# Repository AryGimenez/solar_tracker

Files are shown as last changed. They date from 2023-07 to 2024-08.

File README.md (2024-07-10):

# Solar Tracker

Este es el código y documentación para el proyecto Solar Tracker, que es un dispositivo que se encarga de seguir automáticamente el movimiento del sol para mantener un panel solar siempre orientado hacia él y maximizar la eficiencia de la celda fotovoltaica.

**Descripción del Proyecto**  
El Solar Tracker utiliza un **Arduino** como su controlador principal. Cuenta con dos servomotores **Hitec HS-422**: uno para el movimiento vertical y otro para el movimiento horizontal del panel solar. Además, tiene cuatro fotorresistencias (**LDR 5538**) colocadas estratégicamente para detectar la posición del sol.

El proyecto tiene tres modos de funcionamiento, que se pueden seleccionar mediante botones y se indican mediante LEDs:

- **Modo Manual**: En este modo, los servos están controlados por un módulo Arduino Joystick **(Modelo KY 023)**, permitiendo al usuario realizar el seguimiento del sol de forma manual.

- **Modo Solo Motor Horizontal**: En este modo, el servomotor vertical se detiene, y el servomotor horizontal sigue automáticamente las órdenes proporcionadas por las fotorresistencias para mantener el panel solar orientado horizontalmente hacia el sol.

- **Modo Automático**: En este modo, ambos servomotores siguen automáticamente el movimiento del sol, ajustándose tanto en el eje vertical como en el horizontal para mantener el panel solar siempre en dirección al sol.

El Solar Tracker también incluye un módulo de reloj **Tiny RTC** para mantener la fecha y hora actualizada. Además, cuenta con un sensor de corriente **ACS712** para medir el voltaje, amperaje y potencia del panel solar.

Los datos medidos se guardan en una tarjeta microSD en formato JSON, junto con el lugar físico donde se encuentra el Solar Tracker. La tarjeta microSD también almacena la variable **mIntervaloSensado**, que define el intervalo en minutos en el que se deben guardar los datos.

El dispositivo está equipado con un display **OLED SSD1306** de 0.96" para mostrar información relevante, como el lugar físico, fecha y hora actual, voltaje, amperaje, potencia y nivel de batería. Además, si hay algún problema con la tarjeta SD, se mostrará un mensaje de error en el display.

**Estructura del Proyecto**  
- **Codigo**: Todo el código del Solar Tracker.
- **Diagrama_Electrico**: Esquemas en Fritzing e imágenes de los diagramas esquemáticos y el PCB.
- **Diseño 3D**: Diseños para imprimir la estructura en impresora 3D.
- **Proyecto-Ejemplo**: Código de un proyecto similar que sirve como base, pero con algunas funcionalidades adicionales en este proyecto.
- **SolarTraker-Ejemplo**: Código del proyecto de referencia.

**Instalación y Configuración**  
Para utilizar el Solar Tracker, sigue estos pasos:

1. Conecta los componentes según se indica en el código y asegúrate de tener las bibliotecas adecuadas instaladas en tu entorno de desarrollo.
2. Carga el código del Solar Tracker en tu Arduino Mega 2560 utilizando PlatformIO Labs.
3. Conecta el Arduino a una fuente de alimentación y asegúrate de que todos los componentes estén correctamente conectados.
4. Utiliza los botones para seleccionar el modo de funcionamiento deseado y observa cómo el panel solar sigue automáticamente la posición del sol.
5. El display OLED mostrará información actualizada, incluyendo el lugar físico, fecha y hora actual, voltaje, amperaje, potencia y nivel de batería.
6. Para cambiar la configuración del Solar Tracker, como el intervalo de sensado o la fecha del reloj Tiny RTC, utiliza la APK desarrollada en Python para comunicarte con el dispositivo a través del módulo Bluetooth HM-05.

**APK (Aplicación Python)**  cambiar por el id que va 
La comunicación con el Solar Tracker se realiza mediante una APK desarrollada en Python. La APK puede enviar comandos para cambiar el intervalo de sensado, la fecha del reloj Tiny RTC y el lugar físico del Solar Tracker. Además, puede recibir datos del Solar Tracker en formato JSON, incluyendo la hora y fecha actual, voltaje, amperaje, potencia y los datos almacenados en la tarjeta microSD.

Para desarrollar la APK, se puede utilizar la biblioteca **PySerial** para la comunicación por puerto serie y la biblioteca **Requests** para enviar y recibir datos JSON.

**Notas Finales**  
El proyecto del Solar Tracker es una solución eficiente para maximizar la eficiencia de un panel solar al seguir automáticamente el movimiento del sol a lo largo del día. Con la posibilidad de controlar el dispositivo mediante la APK, se pueden realizar ajustes y recibir información actualizada de manera remota.

Esperamos que este proyecto te sea útil y te inspire en futuros desarrollos. Si tienes alguna pregunta o necesitas ayuda adicional, no dudes en consultar la documentación o preguntar en la comunidad.

¡Disfruta de tu Solar Tracker y el aprovechamiento de la energía solar!

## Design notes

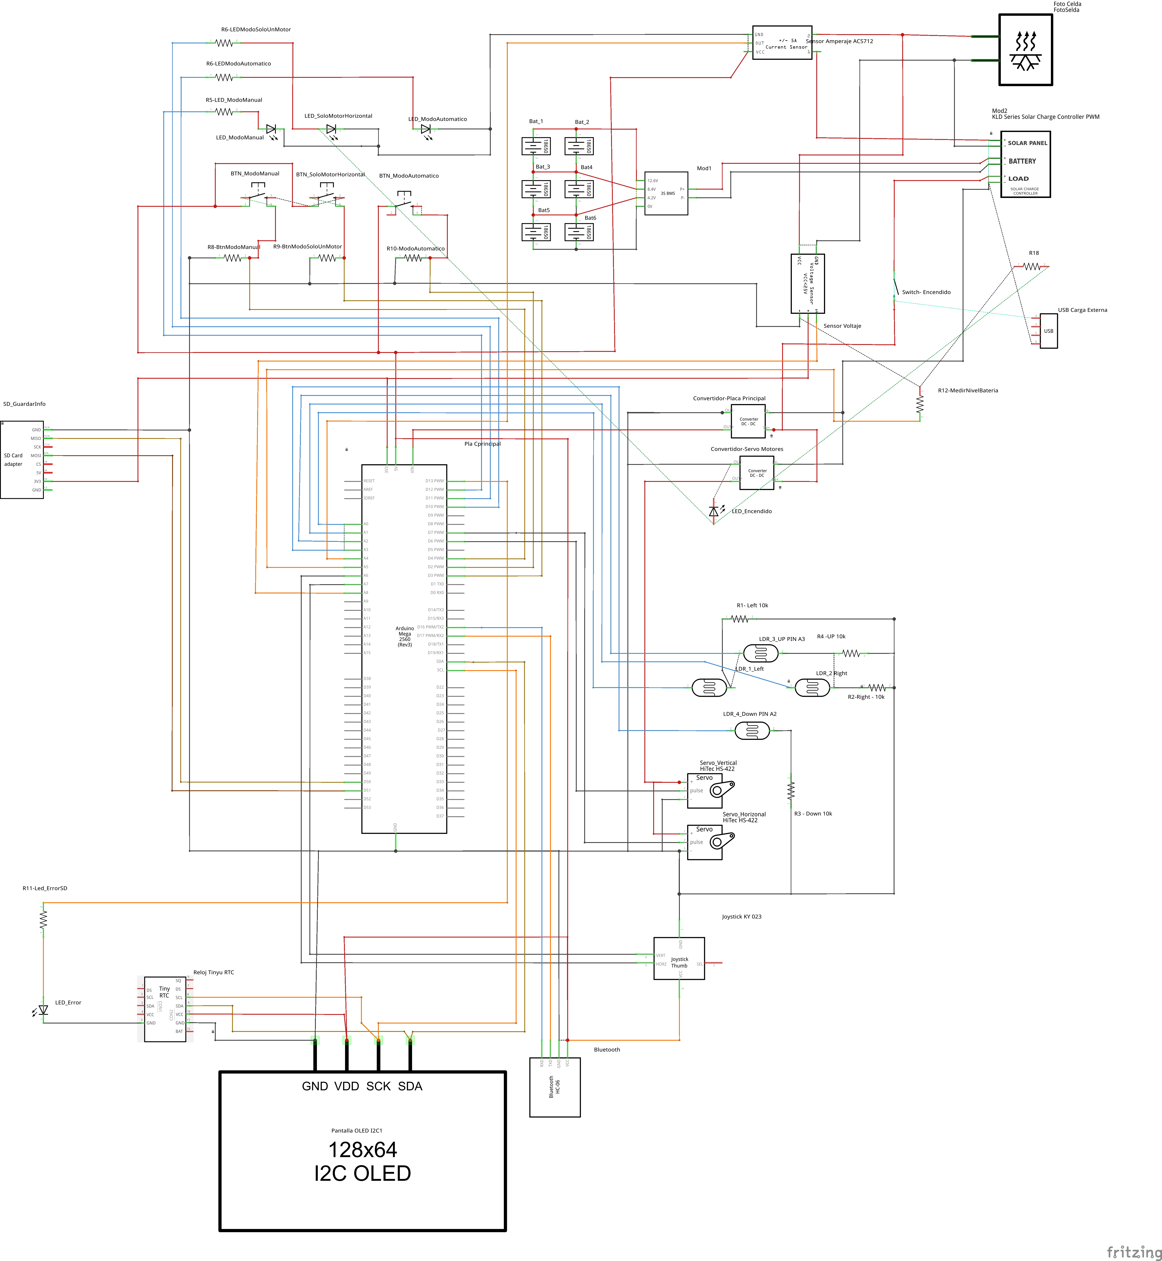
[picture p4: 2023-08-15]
Diagrama_Electrico/Diagrama Solar Tracker - Arduino Mega_Esquemático.jpg

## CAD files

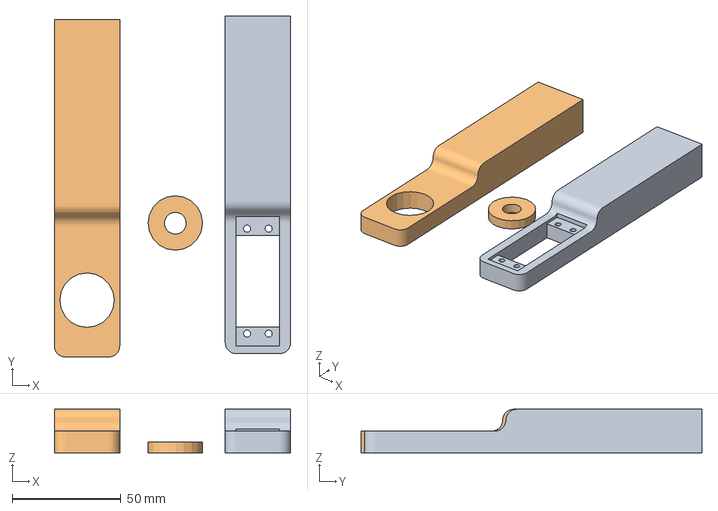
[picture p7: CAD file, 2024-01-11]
Diseño 3d/Para Imprimir/Pilar pantalla eje y motor 155 mm.3mf
108.4 x 156.5 x 20.0 mm
Pilar motor 155mm.stl
Pilar eje 155 mm.stl

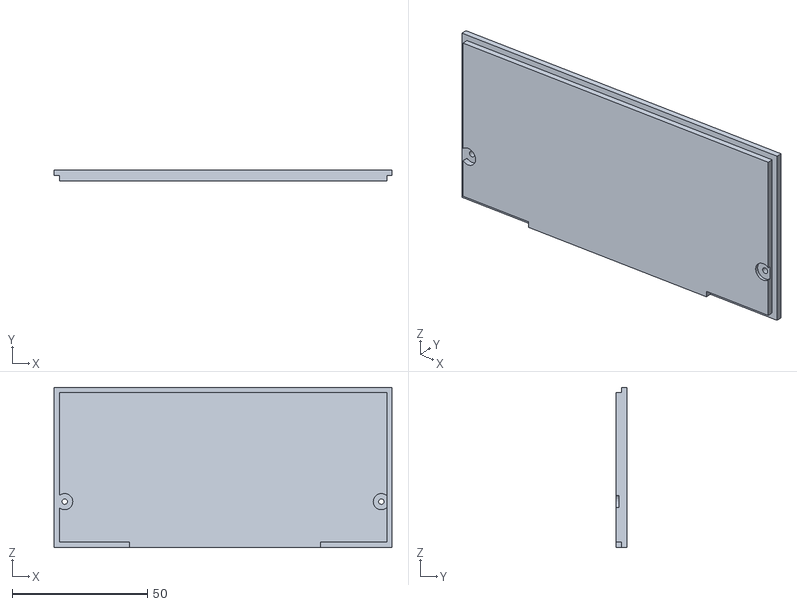
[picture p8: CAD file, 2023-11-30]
Diseño 3d/STL - Diseño 3d/Visor (Tapa).stl
124.9 x 4.00 x 59.2

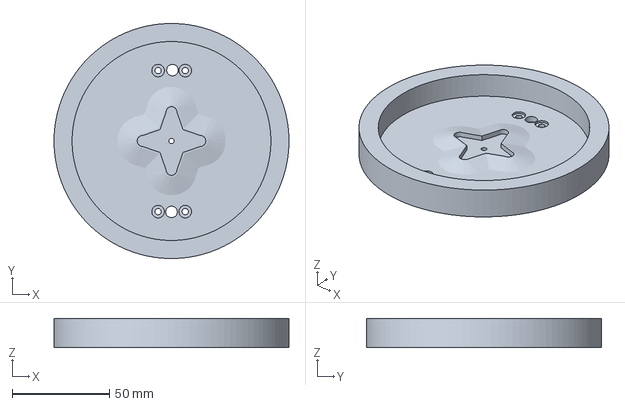
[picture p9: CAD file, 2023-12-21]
Diseño 3d/Para Imprimir/Base Giratoria.3mf
121.0 x 121.0 x 15.0 mm

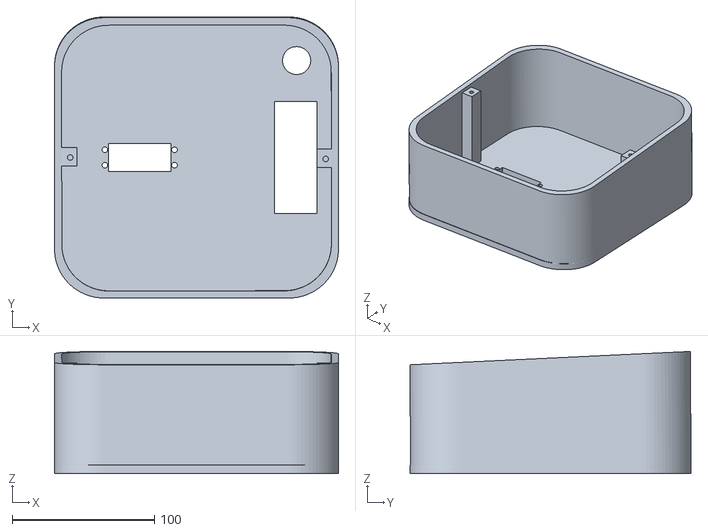
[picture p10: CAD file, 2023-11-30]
Diseño 3d/STL - Diseño 3d/Base Sokar Tracker (8cm pilares sujecion).stl
200.0 x 198.0 x 86.0

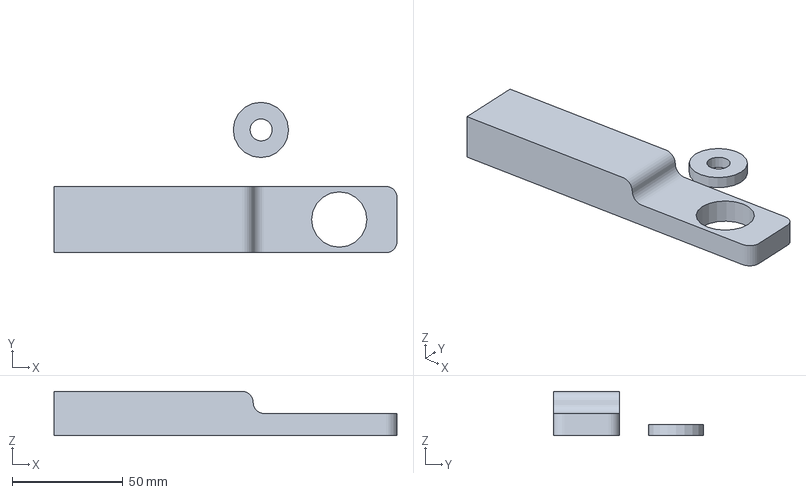
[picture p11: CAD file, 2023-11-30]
Diseño 3d/Para Imprimir/Pilar eje 155 mm.3mf
155.0 x 68.0 x 20.0 mm

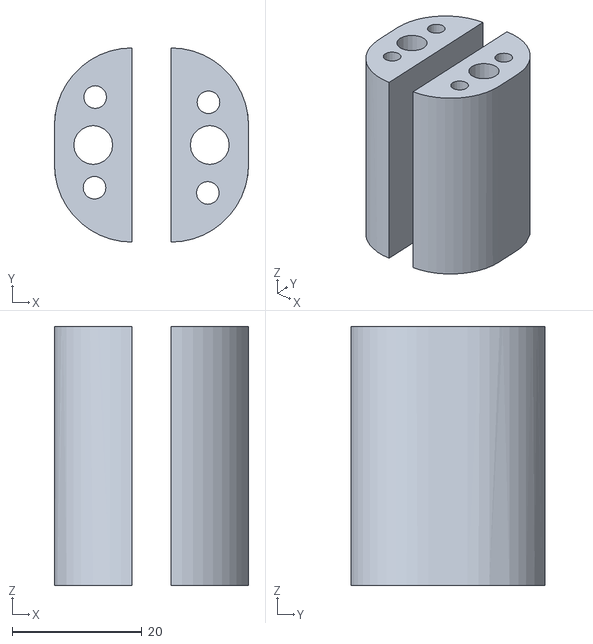
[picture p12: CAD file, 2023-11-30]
Diseño 3d/STL - Diseño 3d/Pilares coneccion Giratorio (40mm).stl
30.0 x 30.0 x 40.0

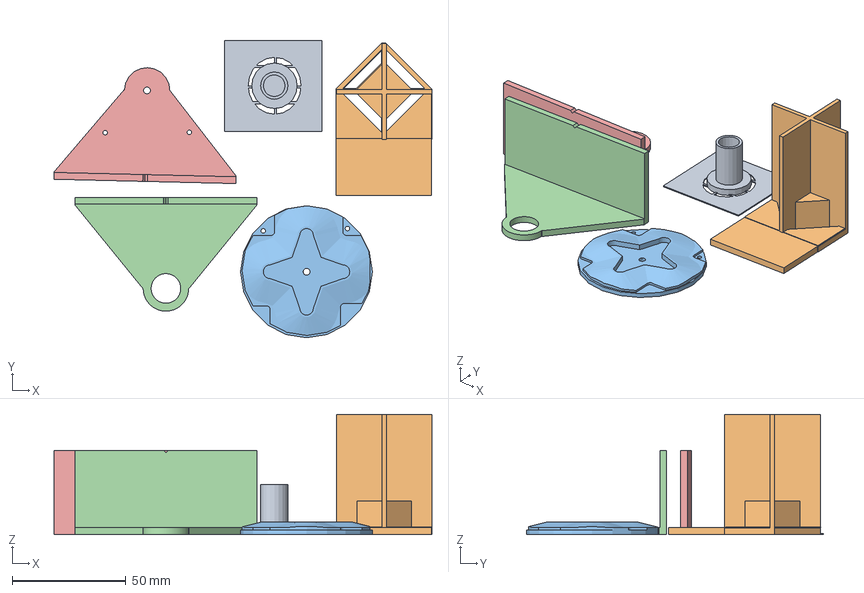
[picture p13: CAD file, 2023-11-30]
Diseño 3d/Para Imprimir/Piesas Chicas (Piesas Sujecion a celda Fotovoltacia - Sensor RGB).3mf
166.1 x 130.7 x 52.8 mm
Soporte Celda Fotovoltaica (Soporte para Eje 2).stl
Sensor RGH luz.stl
Soporte Sujecion motor 2.stl
Soporte Sujecion Eje.stl
Soporte Sujecion motor 1.stl

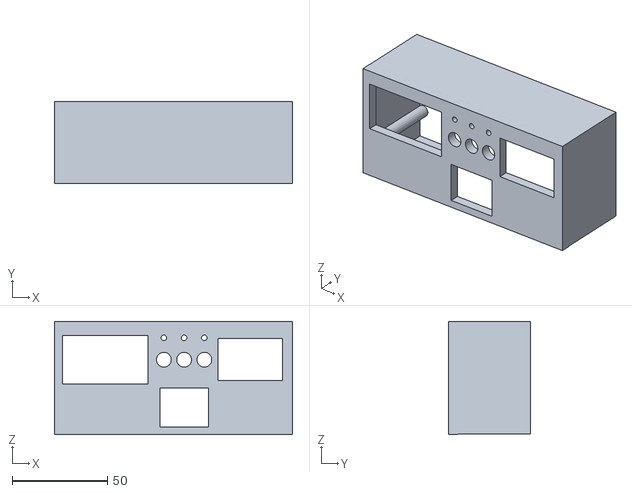
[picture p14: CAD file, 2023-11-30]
Diseño 3d/STL - Diseño 3d/Visor.stl
125.1 x 43.0 x 59.5

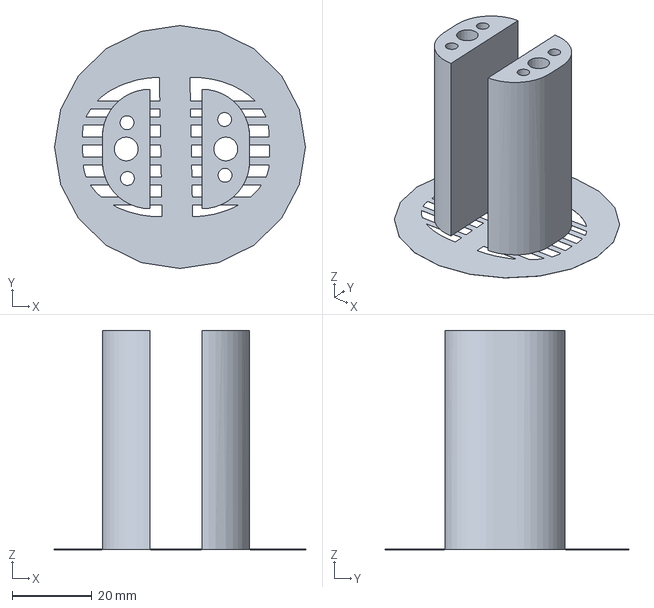
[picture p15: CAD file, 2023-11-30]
Diseño 3d/Para Imprimir/Pilares coneccion Giratorio (55mm) Con Base Imprecion.3mf
63.0 x 61.0 x 55.0 mm

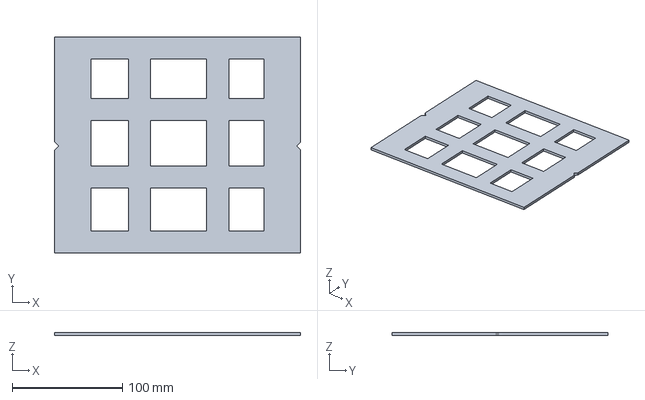
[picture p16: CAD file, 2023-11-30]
Diseño 3d/Para Imprimir/Soporte Celda Fotovoltaica.3mf
223.0 x 196.0 x 3.00 mm

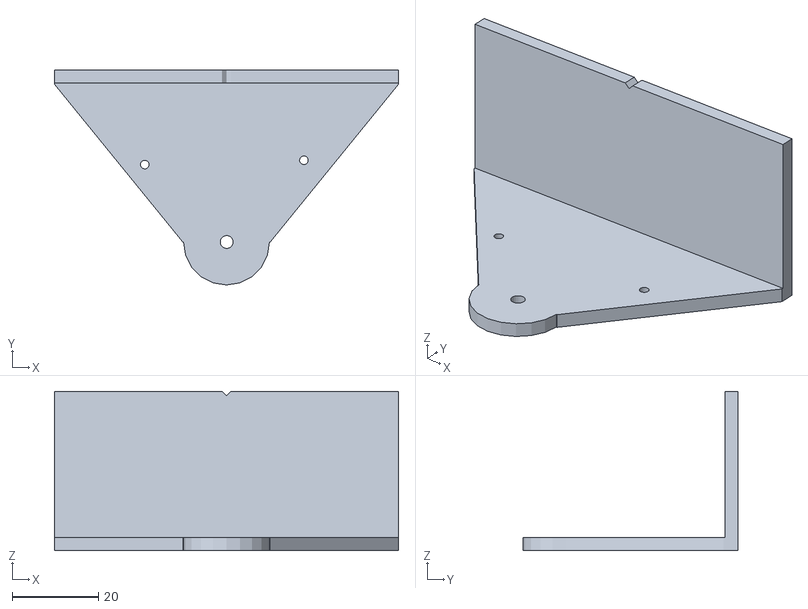
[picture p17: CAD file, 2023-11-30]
Diseño 3d/STL - Diseño 3d/Soporte Sujecion motor 1.stl
80.0 x 50.0 x 37.0

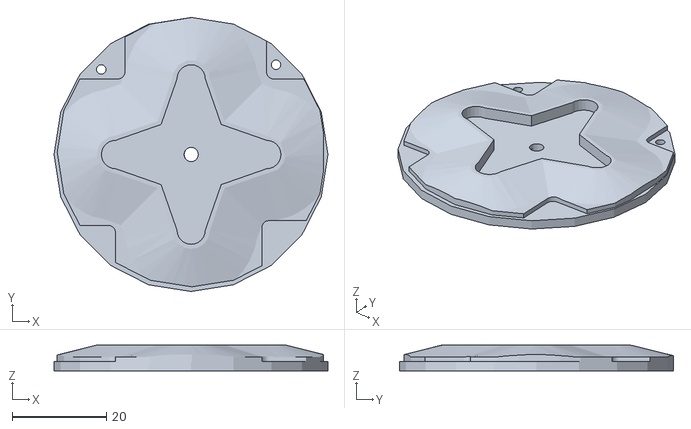
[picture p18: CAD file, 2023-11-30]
Diseño 3d/STL - Diseño 3d/Soporte Sujecion motor 2.stl
58.0 x 58.0 x 5.50

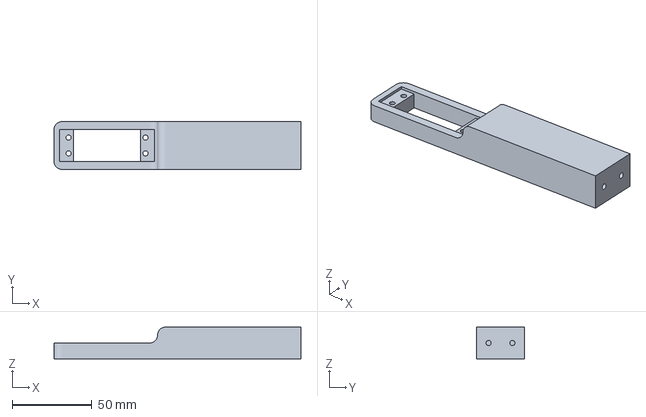
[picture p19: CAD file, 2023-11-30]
Diseño 3d/Para Imprimir/CE3E3V2_Pilar motor 155mm.3mf
155.0 x 30.0 x 20.0 mm

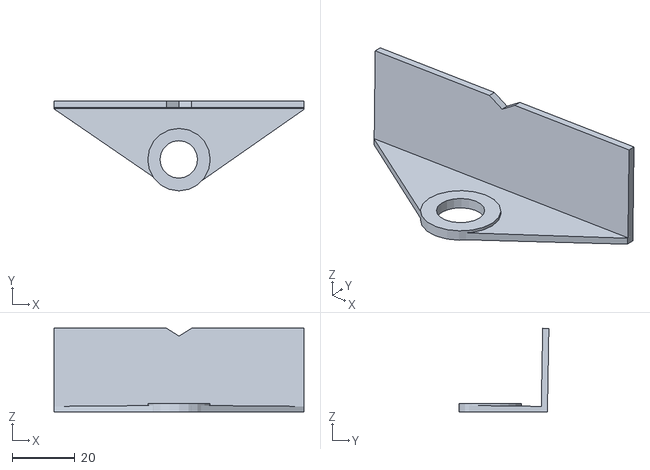
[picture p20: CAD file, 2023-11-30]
Diseño 3d/STL - Diseño 3d/Soporte Celda Fotovoltaica (Soporte para Eje 1).stl
80.0 x 28.7 x 26.7

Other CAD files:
Diseño 3d/STL - Diseño 3d/Pilar eje 155 mm.stl
Diseño 3d/Para Imprimir/Pilar Coneccion Giratorio (40mm).3mf
Diseño 3d/STL - Diseño 3d/Soporte Sujecion Eje.stl
Diseño 3d/Para Imprimir/Base Sokar Tracker (80 cm).3mf
Diseño 3d/Para Imprimir/Base Sokar Tracker.3mf
Diseño 3d/Para Imprimir/Sensor RGH luz.3mf
Diseño 3d/Para Imprimir/Tapa con patitas Base Solar Traker.3mf
Diseño 3d/STL - Diseño 3d/Base Giratoria.stl
Diseño 3d/STL - Diseño 3d/Base Sokar Tracker (Borde 5 mm).stl.stl
Diseño 3d/STL - Diseño 3d/Base Sokar Tracker (Solo - Borde 10 mm).stl
Diseño 3d/STL - Diseño 3d/Base Sokar Tracker (Solo - Borde 5 mm).stl
Diseño 3d/STL - Diseño 3d/Base Solar Tracker (Parte Superior).stl
Diseño 3d/STL - Diseño 3d/Conector para eje metal.stl
Diseño 3d/STL - Diseño 3d/Pilar motor 155mm.stl
Diseño 3d/STL - Diseño 3d/Pilares coneccion Giratorio (40mm) Con Base Imprecion.stl
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

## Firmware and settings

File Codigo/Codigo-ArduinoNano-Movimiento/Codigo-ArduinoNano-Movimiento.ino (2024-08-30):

#include <Servo.h>





// VARIABLES -------------------------------------------------------------------

// ---- Declaraciones de constantes para los pines ----


const int PIN_BTNModoManual = 2;          // Botón para el modo manual
const int PIN_LEDModoManual = 7;          // LED para el modo manual
const int PIN_BTNModoAutomatico = 4;      // Botón para el modo automático
const int PIN_LEDModoAutomatico = 8;      // LED para el modo automático

// Variable para guardar el modo de usos seleccionado
bool modoManualActivo = false;  // MOdo de uso LDR activado por defect\



// ⚡  Sensor voltaje Amperaje ------------------------------

  // Pines para los sensores de amperaje y voltaje
  const int PIN_SensorAmperaje = A6;        // Pin para el sensor de amperaje
  const int PIN_SensorVoltaje = A7;         // Pin para el sensor de voltaje

  // Variables para guardar mediciones de amperaje y voltaje
  float currentAmperage = 0.0;
  float currentVoltage = 0.0;


// ⚡  FIN Sensor voltaje Amperaje ------------------------------


// Pines del joystick KY 023 🕹️ ------------------------------


  const int PIN_JoystickX = A4;             // Pin para el eje X del joystick
  const int PIN_JoystickY = A5;             // Pin para el eje Y del joystick// Pines para los sensores LDR


// 🕹️ FIN ------------------------------


// 📡 Sensor LDR ------------------------------

    // Definición de los pines de las fotorresistencias 🌞
    const int PIN_LDR_Arriba = A0;            // ⬆️ - Pin para el LDR de "Arriba"
    const int PIN_LDR_Izquierda = A3;         // ➡️ - Pin para el LDR de "Izquierda" 
    const int PIN_LDR_Abajo = A2;             // ⬇️ - Pin para el LDR de "Abajo"
    const int PIN_LDR_Derecha = A1;           // ⬅️ - Pin para el LDR de "Derecha"

// 📡 FIN Sensor LDR -----------------------------


// ⚙️ Atributos Servos ------------------------------
  // ⬆️⬇️ 10 Pin Vertical - Ubicado en la pantalla solar
  // ⬅️➡️ 11 Pin Hotizontal - Ubicado En el eje del soporto 

  // Declaraciones para los servos
  const int PIN_ServoHorizontal = 11;       // Pin para el servo horizontal
  const int PIN_ServoVertical = 10;         // Pin para el servo vertical

  // Objetos para controlar los servos
  Servo m_servoHorizontal;
  Servo m_servoVertical;

  // variables para guardar la ultima posicion de los servos
  int m_ServoHorizontalPosicion = 0;
  int m_ServoVerticalPosicion = 0;

  // Definición de constantes para la calibración y los límites de movimiento del servo
  const int MIN_ANGLE = 0;    // Ángulo mínimo del servomotor
  const int MAX_ANGLE = 180;  // Ángulo máximo del servomotor

  // Ajustar estos valores basados en las pruebas con el servo
  int pwmMin = 300;  // Valor PWM mínimo (ajustar según el servo) Defecto 600 
  int pwmMax = 2400; // Valor PWM máximo (ajustar según el servo)


  const int m_umbralSensibilidad = 5;   // Incremento en grados para cada ajuste del servo, utilizado para 
                              // calibrar la sensibilidad del sensor LDR y evitar respuestas 
                              // a pequeñas variaciones

// ⚙️ Fin atributos Servos ------------------------------



//METODOS -------------------------------------------------------------------


// ⚙️ Metodos Servos ------------------------------


  /**
   * @brief moveVertical
   * Funcion para mover el servomotor verticalmente
   * Si 'direction' es positivo (>0), mueve el servo hacia la arriba
   */
  void moveVertical(int direction) {
   
    // Calcula la nueva posición vertical del servomotor,
    // asegurándose de que esté dentro de los límites permitidos.
    // 'm_ServoVerticalPosicion' es la posición actual del servomotor.
    // 'direction' indica la dirección y magnitud del cambio de posición.
    // 'ANGLE_STEP' es la cantidad de grados que el servo debe moverse por cada unidad de 'direction'.
    // 'MIN_ANGLE' y 'MAX_ANGLE' son los límites mínimos y máximos, respectivamente, dentro de los cuales el servomotor puede moverse.
    

    // Guarda la nueva pocicione en sumandole la nueva funcion del angulo 
    int x_NuevaPocicionVertical = direction + m_ServoVerticalPosicion;


    // Verifica que la nueva posición esté en el rango apropiado.
    if (x_NuevaPocicionVertical < MIN_ANGLE || x_NuevaPocicionVertical > MAX_ANGLE)
      return;
      
    // Actualiza la posición del servomotor.
    m_ServoVerticalPosicion = x_NuevaPocicionVertical;

    moverServo(m_ServoVerticalPosicion,)

    // Imprime la nueva posición del servomotor vertical en el monitor serial para depuración y monitoreo.
    Serial.print("Servo Vertical: ");
    Serial.println(m_ServoVerticalPosicion);
  } // Fin de la función 'moveVertical'

  /**
   * @brief moveHorcizontal
   * Funcion para mover el servomotor horizontalmente
   * Si 'direction' es positivo (>0), mueve el servo hacia la derecha
   */
  void moveHorcizontal(int direction) {
    
    // Calcula la nueva posición horizontal del servomotor,
    // asegurándose de que esté dentro de los límites permitidos.
    // 'm_ServoHorizontalPosicion' es la posición actual del servomotor.
    // 'direction' indica la dirección y magnitud del cambio de posición.
    // 'ANGLE_STEP' es la cantidad de grados que el servo debe moverse por cada unidad de 'direction'.
    // 'MIN_ANGLE' y 'MAX_ANGLE' son los límites mínimos y máximos, respectivamente, dentro de los cuales el servomotor puede moverse.


    // Guarda la nueva pocicione en sumandole la nueva funcion del angulo 
    int x_NuevaPocicionHorizontal = direction + m_ServoHorizontalPosicion;


    // Verifica que la nueva posición esté en el rango apropiado.
    if (x_NuevaPocicionHorizontal < MIN_ANGLE || x_NuevaPocicionHorizontal > MAX_ANGLE)
      return;
      
    // Actualiza la posición del servomotor.
    m_ServoHorizontalPosicion = x_NuevaPocicionHorizontal;
   

    moverServo(m_ServoHorizontalPosicion, m_servoHorizontal)
 
    // Imprime la nueva posición del servomotor horizontal en el monitor serial para depuración y monitoreo.
    Serial.print("Servo Horizontal: ");
    Serial.println(m_ServoHorizontalPosicion);
  } // Fin de la función 'moveHorizontal'

  /**
  * 
  **/
  void moverServo(int p_Grados, Servo p_ServoAMover){
    int xPWM_Temp = map(p_Grados, 
      MIN_ANGLE, // Valor mínimo de la posición del servomotor
      MAX_ANGLE, // Valor máximo de la posición del servomotor
      pwmMin, // Valor minimo del PWM
      pwmMax); // Valor maximo del PWM

    // Mueve Servo
    p_ServoAMover.write(xPWM_Temp);

  }

 /**
  * @def controlarSerfosConLDR
  * para controlar servos con el sensor LDR
  **/
    void controlarServosConLDR() {
      // Aquí el código para mover los servos con los sensores LDR
      int valorLDRArriba = analogRead(PIN_LDR_Arriba);
      int valorLDRDerecha = analogRead(PIN_LDR_Derecha);
      int valorLDRAbajo = analogRead(PIN_LDR_Abajo);
      int valorLDRIzquierda = analogRead(PIN_LDR_Izquierda);


      Serial.print("Arriba: ");
      Serial.print(valorLDRArriba);
      Serial.print(" | Derecha: ");
      Serial.print(valorLDRDerecha);
      Serial.print(" | Abajo: ");
      Serial.print(valorLDRAbajo);
      Serial.print(" | Izquierda: ");
      Serial.println(valorLDRIzquierda);
      
      // Determinar la dirección de la luz más intensa de lado vertical
      if (abs(valorLDRArriba - valorLDRAbajo) > m_umbralSensibilidad ) {
        if (valorLDRArriba > valorLDRAbajo) {
          moveVertical(1); // Mover hacia arriba
        } else {
          moveVertical(-1); // Mover hacia abajo
        }
      }

      // Determinar la dirección de la luz más intensa de lado horizontal
      if (abs(valorLDRDerecha - valorLDRIzquierda) > m_umbralSensibilidad) {
        if (valorLDRDerecha > valorLDRIzquierda) {
          moveHorcizontal(1); // Mover hacia la derecha
        } else {
          moveHorcizontal(-1); // Mover hacia la izquierda
        }
      }

    }




    /**
     * @def VerifiarEsadoSero
     * 
     */
    void VerifiarEsadoSero (boolean pVertica){
      
      if (pVertica){
        m_ServoVerticalPosicion = 0;
        moveVertical(0);
        
        for (int i = 0; i < 180; i++)
        {
          delay(1000);
          moveVertical(1);
        }

      }else{
        m_ServoHorizontalPosicion = 0;
        moveHorcizontal(0);
        
        for (int i = 0; i < 180; i++)
        {
          delay(1000);
          moveHorcizontal(1);
        }        
      }
  

      
    }

/**
 * @brief inicializarServos
 * Inicializa los servos y los mueve a la posición inicial.
 */

void inicializarServos() {

   m_servoHorizontal.attach(PIN_ServoHorizontal);             // Adjunta el servo horizInicializa ontal al pin 11
   m_servoVertical.attach(PIN_ServoVertical);               // Adjunta el servo vertical al pin 10
 
  moveHorcizontal(0);

  // Estableser Posición inicial de los servos
   m_servoHorizontal.write(180);             // Posición inicial del servo horizontal
   m_servoVertical.write(180);               // Posición inicial del servo vertical
}

// ⚙️ Fin Servos ------------------------------


// 📡 Sensor LDR ------------------------------

  /**
   * @def verificarSensoresLDR
   * Metodo utilizado para verificar los sentidos Del Sensor LDR  
   */ 
    void verificarSensoresLDR() {
    // Leer los valores analógicos de los sensores LDR
    int valorLDRArriba = analogRead(PIN_LDR_Arriba);
    int valorLDRDerecha = analogRead(PIN_LDR_Derecha);
    int valorLDRAbajo = analogRead(PIN_LDR_Abajo);
    int valorLDRIzquierda = analogRead(PIN_LDR_Izquierda);
    
    // Imprimir los valores leídos - Imprime: "LDR Up: valor, Right: valor, Down: valor, Left: valor"
    Serial.print("LDR Up: " + String(valorLDRArriba) + ", ");
    Serial.print("Right: " + String(valorLDRDerecha) + ", ");
    Serial.print("Down: " + String(valorLDRAbajo) + ", ");
    Serial.println("Left: " + String(valorLDRIzquierda));


    //Esperar 3 segundos
    delay(1000);
  }

  /**
   * @brief iniciarSensorLDR
   * Inicializa los pines utilizados para los sensores LDR.
   * */

  void iniciarSensorLDR() {
    pinMode(PIN_LDR_Arriba, INPUT);
    pinMode(PIN_LDR_Izquierda, INPUT);
    pinMode(PIN_LDR_Abajo, INPUT);
    pinMode(PIN_LDR_Derecha, INPUT); 
   }







// 📡 FIN Sensor LDR ------------------------------







// Metodos joystick KY 023 🕹️ ------------------------------

/** 
 * @def controlarServosConJoystick
 * Controla los servos con el joystick.
 */
void controlarServosConJoystick() {
    int valorX = analogRead(PIN_JoystickX); // Lee el valor del eje X del joystick
    int valorY = analogRead(PIN_JoystickY); // Lee el valor del eje Y del joystick

      // Umbrales para el movimiento del joystick
    int umbralInferior = 400; // Valor debajo del cual se mueve el servo hacia un extremo
    int umbralSuperior = 600; // Valor por encima del cual se mueve el servo hacia el otro extremo



    // Definir topes de movimiento para los servos !!!!!!!!!!!!!!!!!!!!!!!!!!!!!!!!!!!!!!!!!!!!!!!!!!!!!!!!!!!!!!!!!!!!!!!!!!!!!!!!!!!!!!!!!!!!

    // Movimiento Horizontal
    if (valorX < umbralInferior) {
        m_ServoHorizontalPosicion--; // Mueve hacia la izquierda
    } else if (valorX > umbralSuperior) {
        m_ServoHorizontalPosicion++; // Mueve hacia la derecha
    }

    // Movimiento Vertical
    if (valorY < umbralInferior) {
        m_ServoVerticalPosicion--; // Mueve hacia abajo
    } else if (valorY > umbralSuperior) {
        m_ServoVerticalPosicion++; // Mueve hacia arriba
    }

    // Modificar Movimiento Vertical




    // Restringe los valores de los servos a su rango permitido

    // Velocidad de movimiento de eje Vertical En este caso se mueve cada 5 grados
    int m_velocidadMovimiento = 5;
    m_ServoHorizontalPosicion = m_ServoHorizontalPosicion * m_velocidadMovimiento;





     m_ServoHorizontalPosicion = constrain(m_ServoHorizontalPosicion, 0, 180);
    // m_ServoVerticalPosicion = constrain(m_ServoVerticalPosicion, 0, 180);

    // Mueve los servos a las nuevas posiciones
    m_servoHorizontal.write(m_ServoHorizontalPosicion);
    m_servoVertical.write(m_ServoVerticalPosicion);



}

// 🕹️ FIN -----------------------------



// ⚡ Metodos Sensor voltaje Amperaje ------------------------------


  // Lee los valores de los sensores de amperaje y voltaje
  void leerSensores() {
    leerAmperaje();
    leerVoltaje();
  }

  // lee el amperaje del sensor de amperaje
  void leerAmperaje() {
    int sensorValue = analogRead(PIN_SensorAmperaje);
    float voltage = (sensorValue * 5.0) / 1023.0;
    currentAmperage = (voltage - 2.5) / 0.185;
  }

  // lee el voltaje del sensor de voltaje
  void leerVoltaje() {
    int sensorValue = analogRead(PIN_SensorVoltaje);
    currentVoltage = sensorValue * (5.0 / 1023.0) * 5 * 0.927;
  }


  // Muestra datos de los datos de los sensores de 
  // amperaje y voltaje en el monitor serial
  // Amperaje: 0.00 A, Voltaje: 0.00 V
  void mostrarDatos() {
    Serial.print("Amperaje: ");
    Serial.print(currentAmperage);
    Serial.print(" A, Voltaje: ");
    Serial.print(currentVoltage);
    Serial.println(" V");
  }

// ⚡ FIN Metodos Sensor voltaje Amperaje ------------------------------






//  Modo Uso  ---------------------------------------

  /**
   * @brief inicializarPinesModoUso
   * Inicializa los pines utilizados para el modo de uso.
   */
  void inicializarPinesModoUso() {
    pinMode(PIN_BTNModoManual, INPUT);
    pinMode(PIN_LEDModoManual, OUTPUT);
    pinMode(PIN_BTNModoAutomatico, INPUT);
    pinMode(PIN_LEDModoAutomatico, OUTPUT);

    // digitalWrite(PIN_LEDModoManual, HIGH);  // Enciende el LED del modo manual por defecto
    digitalWrite(PIN_LEDModoAutomatico, HIGH);
  }





  /**
   * Actualiza el modo de operación basado en la entrada del usuario.
   * Este método verifica si alguno de los botones de modo ha sido presionado.
   * Si se detecta un botón presionado, el sistema actualiza el modo de uso
   * y cambia la indicación LED correspondiente.
   */
  void actualizarModo() {
    
    // Verifica si el botón para el modo manual ha sido presionado.
    if (digitalRead(PIN_BTNModoManual) == HIGH) {
      // Si el botón de modo manual está presionado, activa el modo manual.
      modoManualActivo = true;

      // Enciende el LED indicador del modo manual.
      digitalWrite(PIN_LEDModoManual, HIGH);

      // Apaga el LED indicador del modo automático.
      digitalWrite(PIN_LEDModoAutomatico, LOW);
    } // fin if modo manual
    
    else if (digitalRead(PIN_BTNModoAutomatico) == HIGH) {
      // Si el botón de modo automático está presionado, desactiva el modo manual.
      modoManualActivo = false;

      // Enciende el LED indicador del modo automático.
      digitalWrite(PIN_LEDModoAutomatico, HIGH);

      // Apaga el LED indicador del modo manual.
      digitalWrite(PIN_LEDModoManual, LOW);
    } // fin if modo automatico


  } // Fin de la función 'actualizarModo'
    

// Fin Modo Uso  ---------------------------------------


//----------------------------------------------------------------------------------------------------------------------------------------

// Configuración inicial
void setup() {
  Serial.begin(9600);
  inicializarPinesModoUso();
  inicializarServos();
  iniciarSensorLDR(); 
  // mostrarDatos();
}


// Loop principal
void loop() {
  // Metodo para Ferificar si los Sensores LDR estan bine
  // es decir si los pines corresponden a las ubicaciones 
  // up Dwon lert joint

  // verificarSensoresLDR();

  

  VerifiarEsadoSero(true);
  VerifiarEsadoSero(false);

    // actualizarModo();

  // Si el modo manual está activo, controla los servos con el joystick.   
  // if (modoManualActivo) {
   //  controlarServosConJoystick();
  // } else {
  //  controlarServosConLDR();
  //}
 
 
  // leerSensores();
  // mostrarDatos();

  //Espear 1 segundo
  delay(1000);

  

}



// Pued

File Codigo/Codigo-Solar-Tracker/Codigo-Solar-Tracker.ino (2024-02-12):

#include <Servo.h> // Mover los Servo
#include <Time.h> // Modulo Reloj
#include <SPI.h> // Bus de Comunicacion SPI
#include <SD.h> //Tarjeta SD


 
 
Servo servo_Vertical;      // create servo object to control a servo (Vertical)
Servo servo_Horizonal;  // create servo object to control a servo (Horizontal)
int val_Vertical=90;        // variable to read the value from the analog pin 
int val_Horizonal=90;       // variable to read the value from the analog pin 

//===============================================================================
const int referenceVolts = 5;
const float R1 = 51000.0; //Resistor #1 (51K) <?>
const float R2 = 100000.0; //Resistor #2 (100K)
const float Ratio = (R1/R2);
const float resistorFactor = ((referenceVolts/Ratio)/1023.0);  // eq 0.014471088

const int TolarencePin = A4; // Use Potentiometer for Tolarence Settings 
const int solarPin = A5;  // +V from Solar Panel connected to analog pin 
float v = 0;



// Archivo donde se va a guardar el Senso

File myFile;


//  LED del Sensor de Seguimiento Solar -  LED lights of the Solar Tracking Sensor
const int LDR_1_Left = A0;        // LDR connected to Analog Pin 0 Left
const int LDR_2_Right = A1;       // LDR connected to Analog Pin 1 Right
const int LDR_3_Down = A2;        // LDR connected to Analog Pin 2 Down
const int LDR_4_Up = A3;          // LDR connected to Analog Pin 3 Up



//  LDR 
int LDR_1_Left_val = 0;
int LDR_2_Right_val = 0;
int LDR_4_Up_val = 0;
int LDR_3_Down_val = 0;
//

// Led que indicadores Aun no se vie que hasen supongo que indica Led LDR_1_Left
//LEDs 10=UP; 11=Right; 12=Left; 13=Down
int ledPins[] = {10,11,12,13};
// 
int dtime = 25; 
int Tolarence = 0;

void setup() 
{ 
  servo_Vertical.attach(5);   // attaches the servo on pin 5 (Elevation) to the servo object 
  servo_Horizonal.attach(6);  // attaches the servo on pin 6 (Horizontal) to the servo object
  
  //Setup LED Pins as OUTPUT
  for (int x = 0; x < 4; x++){
      pinMode(ledPins[x], OUTPUT);  
  }
  Serial.begin(9600); 
} 
 
void loop() 
{ 
  reset_leds();
  read_potentiometer();
  read_voltage();   
  read_LDRs();
  adjust_Servos();
  
  display_status();  
  delay(dtime);                           // waits for the servo to move 
} 

// =========================================================================

// Subs ....


// =========================================================================
void reset_leds(){
 for (int x = 0; x < 4; x++){
        digitalWrite(ledPins[x], LOW); 
 }
}
// =========================================================================
void read_potentiometer(){
// Use Potentiometer for Tolarence Settings  
  Tolarence = analogRead(TolarencePin)/4;
}

// =========================================================================
void read_voltage(){
 v = analogRead(solarPin); 
 v *= resistorFactor;
} // end read_voltage

// =========================================================================
void read_LDRs(){
// Set the LDRs in an x config and label the LDRs from 1-4 
//     \4/
//     1X2
//     /3\1
///arduino LDR Pins 10=UP; 11=Right; 12=Left; 13=Down 
 LDR_1_Left_val = analogRead(LDR_1_Left);
 LDR_2_Right_val = analogRead(LDR_2_Right);
 LDR_3_Down_val = analogRead(LDR_3_Down);
 LDR_4_Up_val = analogRead(LDR_4_Up); 
} //end read_LDRs

// =========================================================================
void adjust_Servos(){
 
int avg_Left_Top =     (LDR_1_Left_val +  LDR_4_Up_val) / 2;        // average value Left_Top
int avg_Left_Botton =  (LDR_1_Left_val +  LDR_3_Down_val) / 2;      // average value Left_Botton
int avg_Right_Top =    (LDR_2_Right_val + LDR_4_Up_val) / 2;        // average value Right_Top
int avg_Right_Botton = (LDR_2_Right_val + LDR_3_Down_val) / 2;      // average value Right_Botton

int dvert = (avg_Left_Top + avg_Right_Top) - (avg_Left_Botton + avg_Right_Botton); // check the diffirence of up and down
int dhoriz = (avg_Left_Top + avg_Left_Botton) - (avg_Right_Top + avg_Right_Botton);// check the diffirence og left and rigt

   // Using the tolarence value stop servo seeking
   // Check Vertical
   if (-1*Tolarence > dvert || dvert > Tolarence){ // check if the diffirence is in the tolerance else change vertical angle
      if ((avg_Left_Top + avg_Right_Top) > (avg_Left_Botton + avg_Right_Botton)){
         //adjust Vertical Servo Down
         digitalWrite(ledPins[3], HIGH); //Blink the Bottom LED
         val_Vertical = ++val_Vertical;
         if (val_Vertical > 179){
             val_Vertical = 179;
         }
      }
      else if ((avg_Left_Top + avg_Right_Top) < (avg_Left_Botton + avg_Right_Botton)){
        //adjust Vertical Servo Up
        val_Vertical= --val_Vertical;
        digitalWrite(ledPins[0], HIGH); //Blink the Top LED
        if (val_Vertical < 1){
            val_Vertical = 1;
         }
      }
      servo_Vertical.write(val_Vertical);
   }
   
   //Check Horizonal
   if (-1*Tolarence > dhoriz || dhoriz > Tolarence){ // check if the diffirence is in the tolerance else change horizontal angle
      if ((avg_Left_Top + avg_Left_Botton) > (avg_Right_Top + avg_Right_Botton)){
         //adjust Horizonal Servo Left
         val_Horizonal = --val_Horizonal;
         digitalWrite(ledPins[1], HIGH); //Blink the Left LED
         if (val_Horizonal < 1){
             val_Horizonal = 1;
         }
      }
      else if ((avg_Left_Top + avg_Left_Botton) < (avg_Right_Top + avg_Right_Botton)){
         //adjust Horizonal Servo Right
         val_Horizonal = ++val_Horizonal;
         digitalWrite(ledPins[2], HIGH); //Blink the Right LED
         if (val_Horizonal > 179){
             val_Horizonal = 179;
         }
      }
      else if ((avg_Left_Top + avg_Left_Botton) == (avg_Right_Top + avg_Right_Botton)){
         // nothing
      }
      servo_Horizonal.write(val_Horizonal);
   }
} // end adjust servos
  
//========================================================================
void display_status(){
 Serial.print("Solar Panel Volts: ");
 Serial.print(v);
 
 Serial.print("  Servo Horizontal: ");
 Serial.print(val_Horizonal);
 Serial.print("  Servo Vertical: ");
 Serial.print(val_Vertical);
 
 Serial.print("  LDR_1_L: ");
 Serial.print(LDR_1_Left_val);
 Serial.print("  LDR_2_R: ");
 Serial.print(LDR_2_Right_val);
 Serial.print("  LDR_3_D: ");
 Serial.print(LDR_3_Down_val);
 Serial.print("  LDR_4_U: ");
 Serial.print(LDR_4_Up_val);
 
 Serial.print("  Tolarence: ");
 Serial.println(Tolarence);
} //end display status

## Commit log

2023-07-12 Iniciar proyecto de Solar Tracker con diagrama eléctrico en Fritzing - Start Solar Tracker project with electrical diagram in Fritzing
    [Diagrama Solar Tracker.fzz]
2023-07-12 Avanzar en el diagrama - Progress on the diagram
    [Diagrama Solar Tracker.fzz]
2023-07-12 Agregué el display SSD1306 pantalla OLED - Added SSD1306 OLED display
    [Diagrama Solar Tracker.fzz]
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2023-07-13 Trabajando en el diagrama eléctrico y asignando nombres de variables a los pines del Arduino - Working on the electrical diagram and assigning variable names to Arduino pins
    [Diagrama Solar Tracker.fzz]
2023-07-13 Continuar trabajo en el diagrama eléctrico y agregar módulo SD - Continue work on the electrical diagram and add SD module
    [Diagrama Solar Tracker.fzz]
2023-07-14 Terminar el diagrama eléctrico - Finish the electrical diagram
    [Diagrama Solar Tracker.fzz]
2023-07-14 Avance con el diagrama eléctrico, falta : Medición de Voltaje, Tensión en celda fotovoltaica, Como se va a alimentar la electrónica de las baterías. Representar las baterías en el diagrama - Avance c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
    [Diagrama Solar Tracker.fzz]
2023-07-15 Casi terminé el diagrama, me está quedando graficar la conexión de los botones para los modos de funcionamiento. Y el botón de apagado - I almost finished the diagram, I am left to graph the connecti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
    [Diagrama Solar Tracker.fzz]
2023-07-15 Estuve trabajando en la parte de los botones en el diagrama - I was working on the buttons part in the diagram
    [Diagrama Solar Tracker.fzz]
2023-07-16 Termine el esquema eléctrico, Empiezo con el código - Finish the electrical schematic, I start with the code
    [Diagrama Solar Tracker.fzz]
2023-07-18 Estuve trabajando en el código, decidí usar PlatformIO para poder usar Visual Studio Code. Y además me da otras prestaciones que facilita el trabajo con las bibliotecas - I was working on the code, I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
    [Diagrama Solar Tracker-2.fzz, Diagrama Solar Tracker.fzz]
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2023-07-19 Subo el directorio con el código de ejemplo que encontré. Dentro está la URL del directorio del repositorio - I upload the directory with the sample code I found. Inside is the URL of the repository 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
    [SolarTraker Base.stl, SolarTraker BaseGiratoria.stl, SolarTraker Columna1.stl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]
2023-07-20 Modifique el esquema eléctrico para agregar un Led para avisar cuando la tarjeta SD no funciona - Modify the electrical diagram to add a Led to warn when the SD card does not work
    [Diagrama Solar Tracker.fzz]
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2023-08-01 Estuve trabajando en el diagrama eléctrico para definir la parte de la carga del proyecto, es decir, Las Celdas fotorresistentes y las baterías como van a alimentar el proyecto - I was working on the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
    [Diagrama Solar Tracker.fzz]
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2023-08-15 Inicie a trabajar en el proyecto nuevamente luego de formatear el sistema operativo - Inicie a trabajar en el proyecto nuevamente luego de formatear el sistema operativo
    [Diagrama Solar Tracker-2.fzz, Diagrama Solar Tracker-3.fzz, Diagrama Solar Tracker.fzz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]
2023-08-21 Estoy trabajando en él principalmente en el archivo main.cpp e corrigiendo el código en las librerías que cree para que compile el código - I'm working on it mainly on the main.cpp file and correctin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
    [main.cpp]
2023-09-07 Estoy trabajando en el diseño 3d para imprimir - I am working on the 3d design for printing
    [Columna Panel Solar Derecha Motor.3mf]
2023-09-07 Sigo trabajando en los archivos de impresión Tengo la tapa inferior con patitas - I'm still working on the print files I have the bottom cover with little legs
    [Base Sokar Tracker.3mf, Tapa con patitas Base Solar Traker.3mf]
2023-09-11 Estuve trabajando con los diseños a imprimir, borré los archivos que no eran necesarios - I was working with the designs to print, I deleted the files that were not necessary
    [BASE CERRADA.stl, Base Sokar Tracker.stl, Base.blend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]
2023-09-15 Sigo trabajando en los diseños 3d para imprimir. La base con patas está pronta y voy a seguir con la base del solar tracker - I'm still working on 3D designs to print. The base with legs is ready and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
    [Base Giratoria.stl, Base Sokar Tracker.3mf, Base Sokar Tracker.stl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]
2023-09-25 Elimine el dierectorio por problema de conflicto con Windows
2023-11-30 Estuve trabajando en la parte de impresiones Acomode las Impresiones
    [Base Giratoria.3mf, Base Sokar Tracker (80 cm).3mf, Base Sokar Tracker (8cm pilares sujecion).stl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]
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2023-12-21 Estoy actualizando los diagramas eléctrico contemplando el cambio de microcontrolador a nano y el módulo Wifi de android
    [Base Giratoria.3mf, Diagrama Solar Tracker - nodemcu-v3 Principal - nano Secundario.fzz, Diagrama Solar Tracker - Arduino Mega.fzz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]
2023-12-21 Prueba ---------------
    [Diagrama Solar Tracker - nodemcu-v3 Principal - nano Secundario.fzz]
2023-12-21 Subí el diagrama de la torre con linux. Hay que meterle al diagrama falta bastante
    [Diagrama Solar Tracker - nodemcu-v3 Principal - nano Secundario.fzz]
2024-01-10 Estoy trabajando en el código nuevo para la versión más reducida con Arduino nano - Estou trabalhando em um novo código para a versão menor com Arduino nano
    [Diagrama Solar Tracker - nodemcu-v3 Principal - nano Secundario.fzz]
2024-01-11 Estuve trabajando en el código para la nueva versión del solar tracker reducido. Voy a subir el código para continuar en la torre - Tenho trabalhado no código da nova versão do rastreador solar reduz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
    [Diagrama Solar Tracker - Arduino Nano.fzz, Pilar pantalla eje y motor 155 mm.3mf]
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2024-02-13 Ya corregi los errores falta probar
    [Codigo-ArduinoNano-Movimiento.ino]
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2024-07-06 Estuve trabajando en el código porque el solar tracker no se movía correctamente. Falta revisar comportamiento y corregir si es necesario - I was working on the code because the solar tracker was not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
    '
    [Codigo-ArduinoNano-Movimiento.ino]
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2024-07-10 Estoy solucionando el desperfecto que no esta siguiendo al sol. - am solving the problem that is not following the sun.
    Revisar
    // Ajustar estos valores basados en las pruebas con el servo
    int pwmMin = 300; // Valor PWM mínimo (ajustar según el servo) Defecto 600
    int pwmMax = 2400; // Valor PWM máximo (ajustar según el servo)
    Y la lógica de movimiento
    void moveVertical(int direction)
    void moveHorcizontal(int direction)
    void controlarServosConLDR()
    --
    Review
    // Adjust these values based on testing with the servo
    int pwmMin = 300; // Minimum PWM value (adjust according to servo) Default 600
    int pwmMax = 2400; // Maximum PWM value (adjust according to servo)
    And the
    [Codigo-ArduinoNano-Movimiento.ino]
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
